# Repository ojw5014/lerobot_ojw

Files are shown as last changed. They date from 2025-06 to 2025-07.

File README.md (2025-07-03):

<p align="center">
  New image
  Open-Snake preview
</p>

# 🤖 Build Your Own Powerful Robot – Affordable & Modular

Ever dreamed of building a fully functional robot using official DYNAMIXEL servos?  
Here’s your chance to do it with a **compact budget and high performance**.

---

## 💰 Total Estimated Cost  
**₩362,778 KRW ≈ $263.17 USD** *(as of June 19, 2025 exchange rate)*  
💡 *That’s the price of a mid-range tablet — but you get a full robot setup!*

---

## 📦 What's Included

| Category | Item | Quantity | Unit Price (KRW) | Subtotal (KRW) | Approx. USD |
|---|---|---|---|---|---|
| **Controller**  | OpenRB-150 | 1 | ₩27,500 | ₩27,500 | $19.95 |
| **Leader Motor**| XL330-M288-T | 6 | ₩26,400 | ₩158,400 | $114.91 |
| **Follower Motors** | XL430-W250-T | 3 | ₩31,900 | ₩95,700 | |
| | XL330-M288-T | 3 | ₩26,400 | ₩79,200 | |
| | **Subtotal (Follower)**  | | | ₩174,900 | $126.88 |
| **Power Supply**| LM317 DC-DC Converter | 2 | ₩1,978 | ₩3,956 | Included |

---

### 💡 Notes
- Prices are based on Korean retail as of **June 19, 2025**.
- USD conversion uses approximate exchange rate of **₩1,378 per $1**.
- Shipping, VAT, or customs not included.

---

## 🎬 Watch It in Action

See the robot moving in real life!

[Click to watch on YouTube](https://youtube.com/shorts/-wr70fOUUQk?si=YxOiGwE313GlAKYQ)

<a href="https://youtube.com/shorts/-wr70fOUUQk?si=YxOiGwE313GlAKYQ" target="_blank">
  Watch on YouTube
</a>

---

## 🧩 How to Assemble LeRobot OJW

Ready to assemble your own LeRobot?

👉 **[Watch the Full Step-by-Step Assembly Video on YouTube](https://youtu.be/AQsma9fiuLw?si=pPNlVMTZPPUCAD57)**

<a href="https://youtu.be/AQsma9fiuLw?si=pPNlVMTZPPUCAD57" target="_blank">
  Assembly Video
</a>

---

## 🛒 Purchase Links

### 🔌 Controller – OpenRB-150  
  
[Buy on Robotis](https://www.robotis.com/shop/item.php?it_id=902-0183-000)

---

### ⚡ Power – LM317 DC-DC Converter  
  
[Buy on AliExpress](https://ko.aliexpress.com/item/1005006562900614.html)

---

### 🤖 Servo Motor – XL330-M288-T  
  
[Buy on Robotis](https://www.robotis.com/shop/item.php?it_id=902-0163-000)

---

### 💪 High-Torque Motor – XL430-W250-T  
  
[Buy on Robotis](https://www.robotis.com/shop/item.php?it_id=902-0135-000)

---

## 🎯 Why This Setup?
- ✅ **Budget-Friendly**: Professional-grade servos at a hobbyist-friendly price  
- 🔧 **Modular & Expandable**: Build, test, and evolve your robot  
- 📚 **Perfect for Education, Research, and Prototyping**  
- 🛠️ **All official parts** – No knockoffs, just reliability

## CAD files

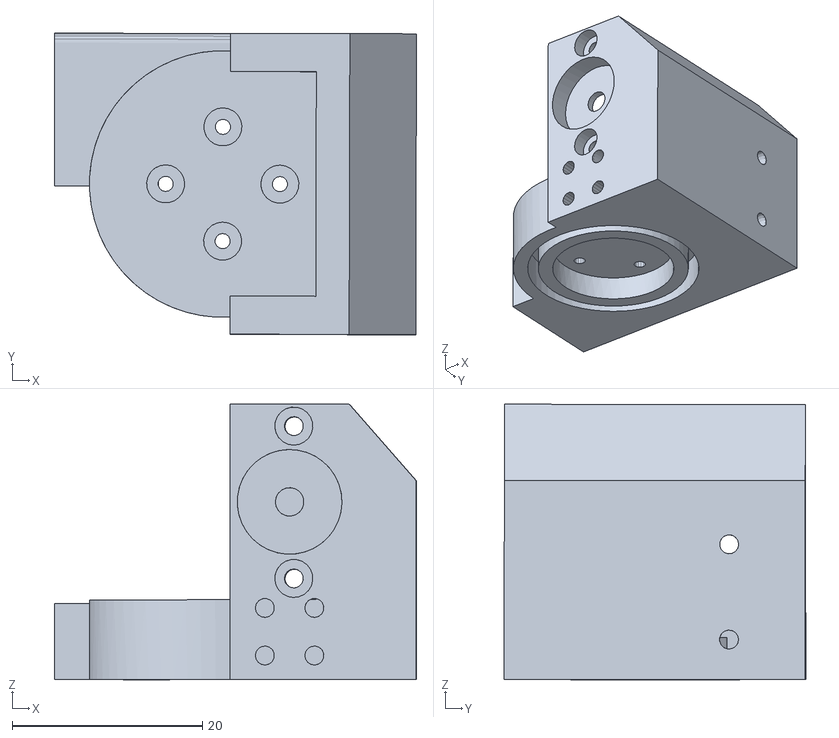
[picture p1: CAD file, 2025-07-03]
lerobot_ojw_stl_v1.1/follower/hand2_base.stl
38.0 x 31.7 x 28.9

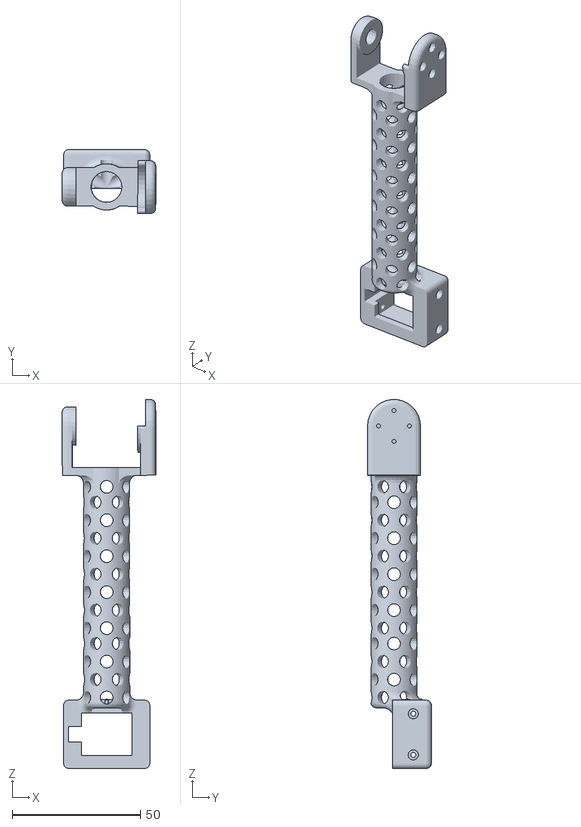
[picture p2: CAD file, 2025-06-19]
lerobot_ojw_stl_v1.1/leader/leader_2.stl
36.5 x 24.9 x 143.6

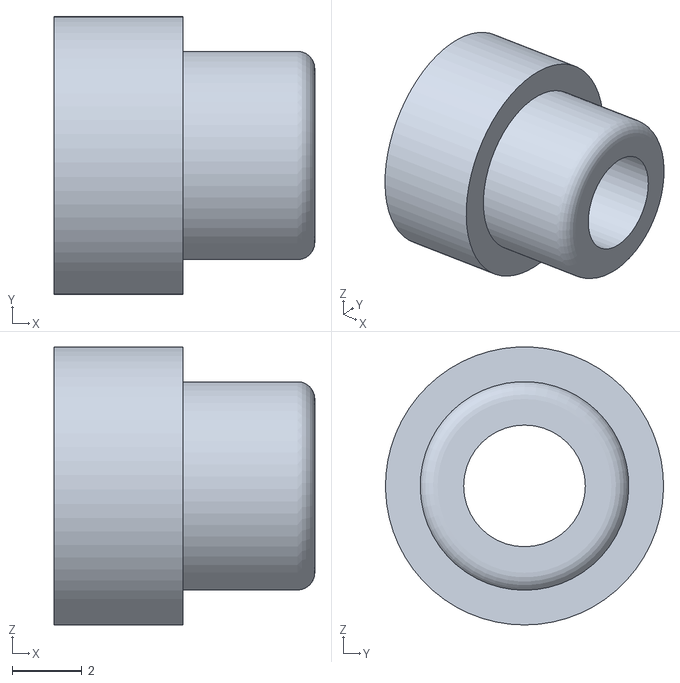
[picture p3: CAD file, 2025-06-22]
lerobot_ojw_stl_v1.1/x330_horn.stl
7.50 x 8.00 x 7.99

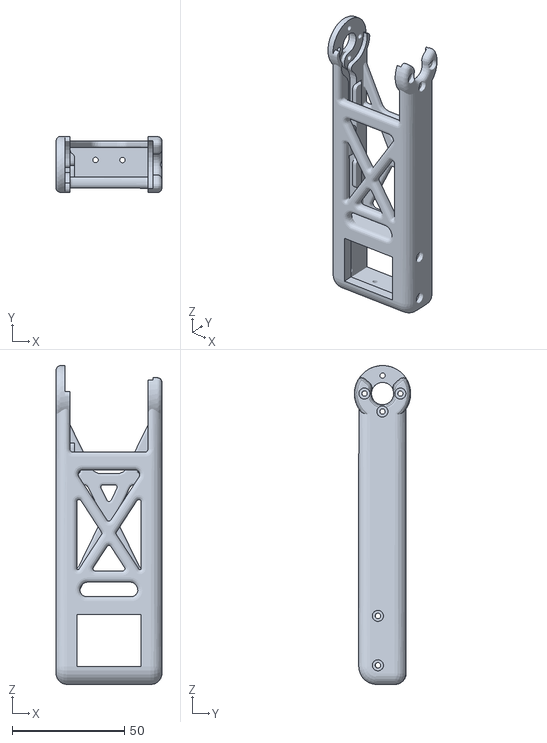
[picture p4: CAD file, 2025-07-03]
lerobot_ojw_stl_v1.1/follower/follower_2.stl
47.3 x 25.1 x 142.0

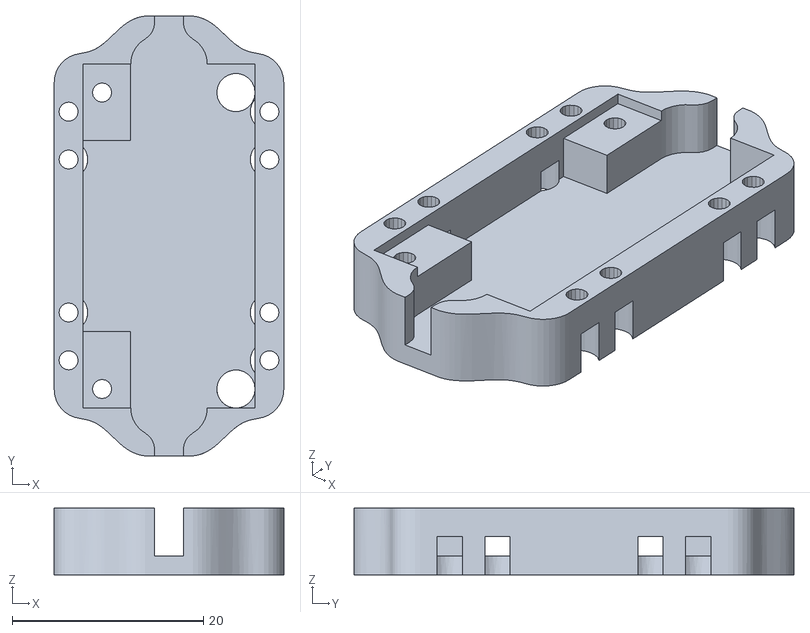
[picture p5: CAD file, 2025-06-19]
lerobot_ojw_stl_v1.1/leader/dcdc_cover_bottom.stl
24.0 x 46.0 x 7.00

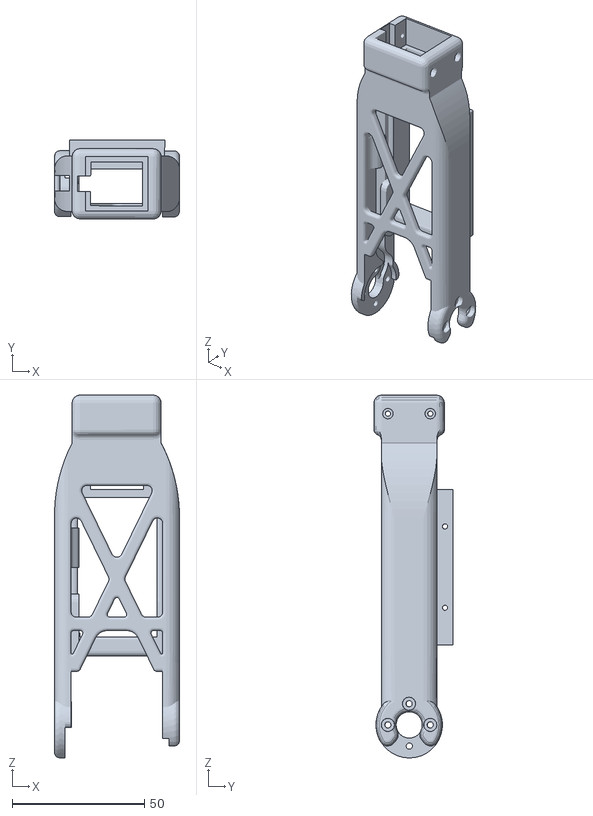
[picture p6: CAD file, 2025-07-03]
lerobot_ojw_stl_v1.1/follower/follower_3.stl
47.3 x 29.9 x 137.1

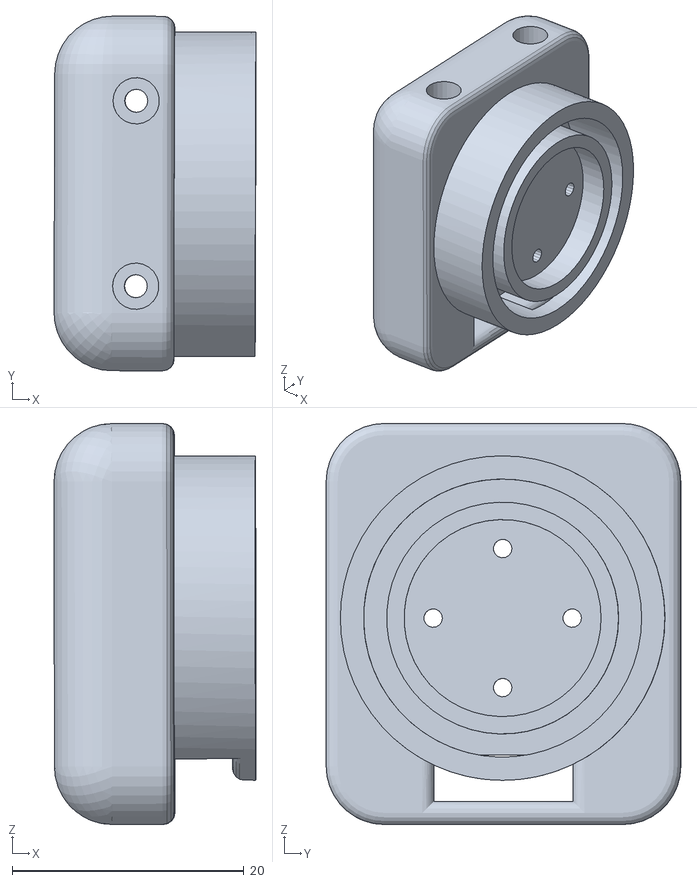
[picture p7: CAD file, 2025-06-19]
lerobot_ojw_stl_v1.1/leader/leader_4.stl
17.4 x 30.6 x 34.6

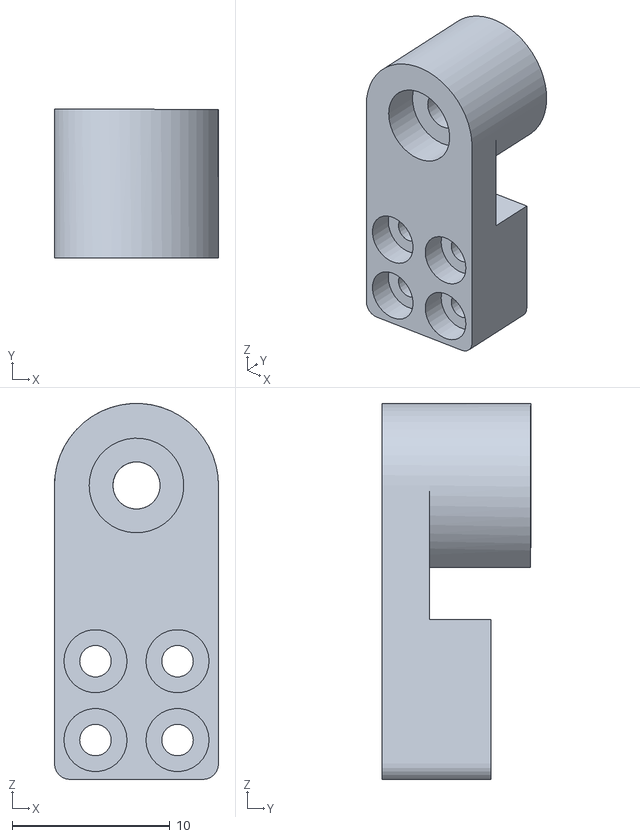
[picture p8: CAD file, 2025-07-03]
lerobot_ojw_stl_v1.1/follower/hand2_guide.stl
10.4 x 9.43 x 23.8

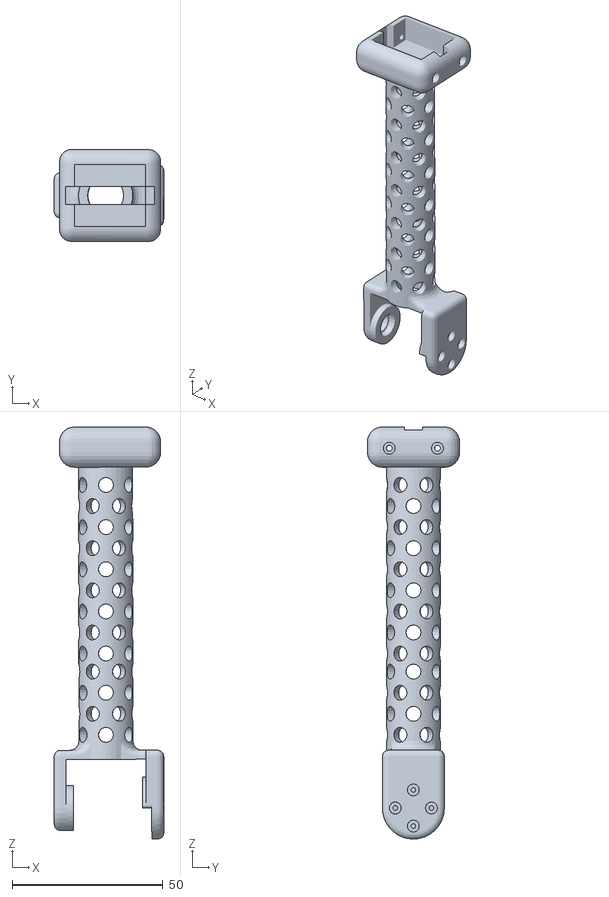
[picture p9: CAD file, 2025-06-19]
lerobot_ojw_stl_v1.1/leader/leader_3.stl
36.5 x 30.7 x 136.8

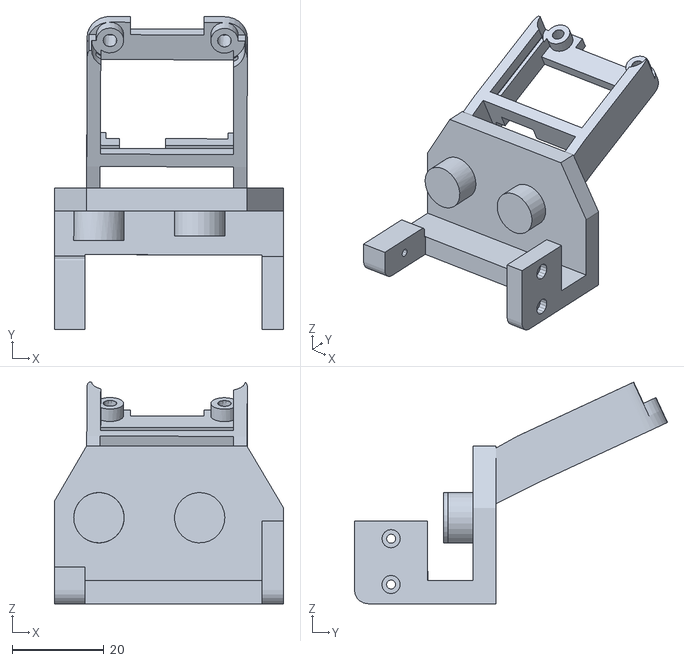
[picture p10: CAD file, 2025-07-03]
lerobot_ojw_stl_v1.1/follower/hand2_Camera.stl
50.0 x 68.4 x 48.4

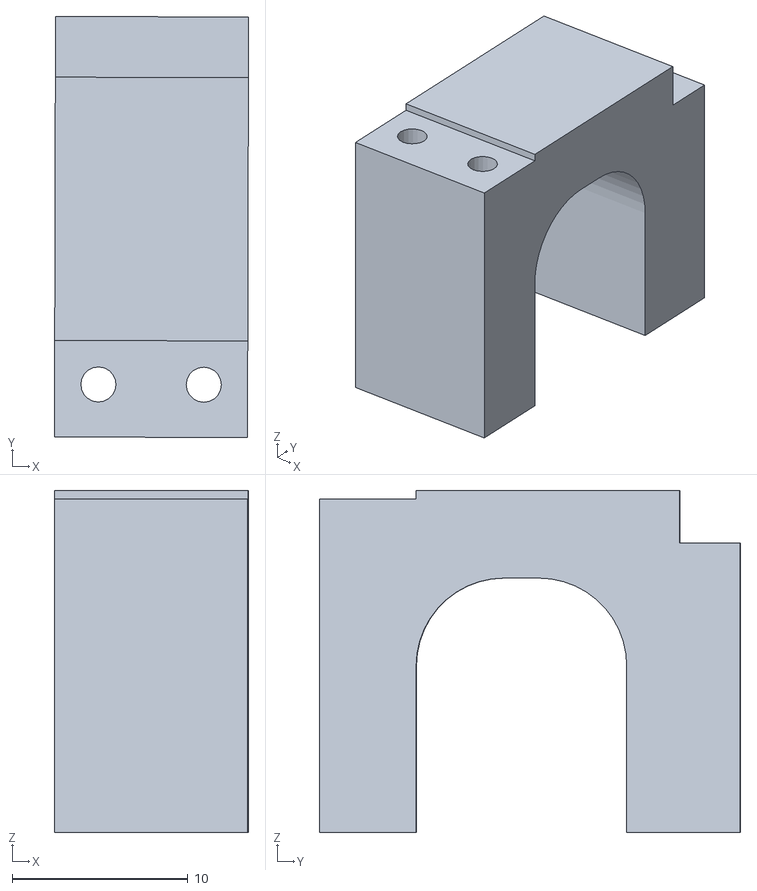
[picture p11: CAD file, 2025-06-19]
lerobot_ojw_stl_v1.1/leader/leader_gun_part_slot.stl
11.1 x 24.0 x 19.5

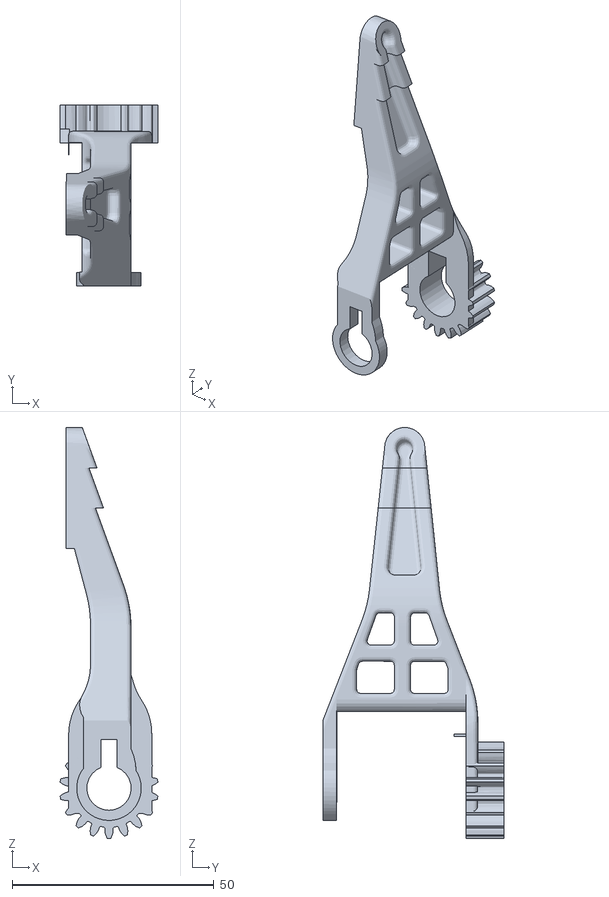
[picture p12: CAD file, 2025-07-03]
lerobot_ojw_stl_v1.1/follower/finger2_dummy.stl
24.3 x 44.9 x 101.9

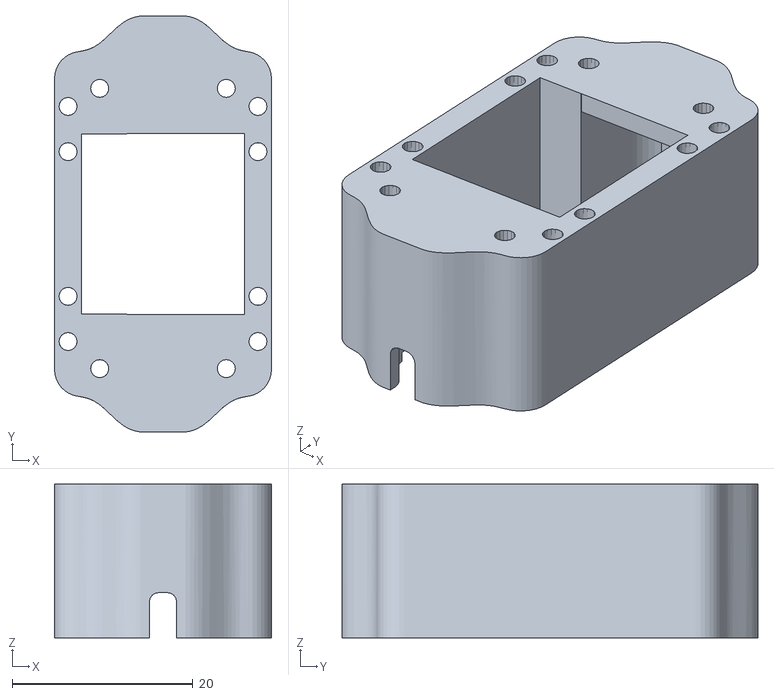
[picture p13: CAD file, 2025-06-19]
lerobot_ojw_stl_v1.1/leader/dcdc_cover_top.stl
24.0 x 46.0 x 17.0

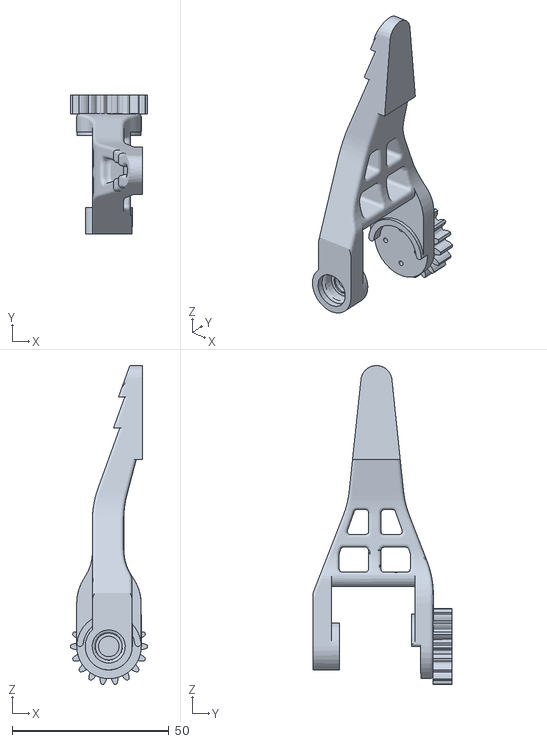
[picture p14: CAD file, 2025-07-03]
lerobot_ojw_stl_v1.1/follower/finger2.stl
24.5 x 44.4 x 101.8

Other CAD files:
lerobot_ojw_stl_v1.1/leader/Release_leg_link.stl
lerobot_ojw_stl_v1.1/follower/follower_4.stl
lerobot_ojw_stl_v1.1/leader/leader_finger.stl
lerobot_ojw_stl_v1.1/follower/follower_3_cover.stl
lerobot_ojw_stl_v1.0/follower/follower_camera_release (1).stl
lerobot_ojw_stl_v1.0/follower/follower_hand0.stl
lerobot_ojw_stl_v1.0/follower/follower_hand1.stl
lerobot_ojw_stl_v1.1/follower/follower_0.stl
lerobot_ojw_stl_v1.1/follower/follower_1.stl
lerobot_ojw_stl_v1.1/leader/leader_0.stl
lerobot_ojw_stl_v1.1/leader/leader_1.stl
lerobot_ojw_stl_v1.1/leader/leader_gun_with_touch.stl

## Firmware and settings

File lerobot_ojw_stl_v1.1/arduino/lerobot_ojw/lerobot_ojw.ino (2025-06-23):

/*

*/
//#include <Dynamixel2Arduino.h>



#include <stdarg.h>
#include <ojw.h>



#define DXL_BUS Serial1
#define USB Serial
#define DXL_PACKET_BUFFER_LENGTH  1024




uint8_t packet_buffer[DXL_PACKET_BUFFER_LENGTH];
unsigned long led_update_time = 0;

//Dynamixel2Arduino dxl(DXL_BUS);

int m_nCmd = 0; // 1 : Command, 0: Usb 2 Dynamixel

int _BTN_TOUCH = 3;

int _ON = LOW;
int _OFF = HIGH;

CProtocol2 m_CMot;
// CTimer m_CTmr;
// CTimer m_CTmr_SW;

void setup() {
  pinMode(_BTN_TOUCH, INPUT);

  USB.begin(57600);

  // m_CTmr.Set();
  ///////////////////////////
  

  // m_CMot.SyncRead("11,12,13,14,15,16");
  // m_CMot.Load("home.txt");
  dxl.begin(USB.baud());
}

void CheckSw()
{
  if (m_nCmd == 1) 
  {
    if (digitalRead(_BTN_TOUCH) == LOW)  
    { 
      //Serial.print("LOW");
      m_CMot.Open(1000000);
      // m_CMot.SetTorq(true);
      m_CMot.SetTorq_On("11,12,13,14,15,16");
      m_CMot.Close();
      //dxl.torqueOn(254);
      m_nCmd = 0;
      // delay(100); // 채터링 방지용
      digitalWrite(LED_BUILTIN, 0);
    }    
  }
  else
  {
    if (digitalRead(_BTN_TOUCH) == HIGH)  
    {
      //Serial.print("HIGH");
      m_CMot.Open(1000000);
      // m_CMot.SetTorq(false);
      m_CMot.SetTorq_Off("11,12,13,14,15,16");
      m_CMot.Close();
      // dxl.torqueOff(254);
      m_nCmd = 1;
      // delay(100); // 채터링 방지용
      digitalWrite(LED_BUILTIN, 1);
    }
  }
}
// ==========================================================================================
// Copyright 2022 ROBOTIS CO., LTD.
//
// Licensed under the Apache License, Version 2.0 (the "License");
// you may not use this file except in compliance with the License.
// You may obtain a copy of the License at
//
//     http://www.apache.org/licenses/LICENSE-2.0
//
// Unless required by applicable law or agreed to in writing, software
// distributed under the License is distributed on an "AS IS" BASIS,
// WITHOUT WARRANTIES OR CONDITIONS OF ANY KIND, either express or implied.
// See the License for the specific language governing permissions and
// limitations under the License.

void loop() {
  CheckSw();
  // if (m_nCmd == 0)
  // {
    // put your main code here, to run repeatedly:
    dataTransceiver();

    if(USB.baud() != dxl.getPortBaud()) {
      dxl.begin(USB.baud());
    }
  // }
  // else
  // {
  // }    
}

void dataTransceiver()
{
  int length = 0;
  int i = 0;

  // USB -> DXL
  length = USB.available();
  if( length > 0 )
  {
    for(i = 0; i < length; i++)
    {
      DXL_BUS.write(USB.read());
    }
    ledStatus();
  }

  // DXL -> USB
  length = DXL_BUS.available();
  if( length > 0 )
  {
    if( length > DXL_PACKET_BUFFER_LENGTH )
    {
      length = DXL_PACKET_BUFFER_LENGTH;
    }
    for(i = 0; i < length; i++)
    {
      packet_buffer[i] = DXL_BUS.read();
    }
    USB.write(packet_buffer, length);
    ledStatus();
  }
}

void ledStatus()
{
  return;
  if((millis() - led_update_time) > 200 )
  {
    digitalWrite(LED_BUILTIN, 1);
    led_update_time = millis();
  } else {
    digitalWrite(LED_BUILTIN, 0);
  }
}

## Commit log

2025-06-19 lerobot_ojw_v1.0 최초 릴리즈
    [Release_leg_link.stl, dcdc_cover_bottom.stl, dcdc_cover_top.stl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]
2025-06-22 horn 부품 추가(빠진것)
    [x330_horn.stl]
2025-06-23 upload - arduino (USB2Dynamixel with touch sensor)
    upload - arduino (USB2Dynamixel with touch sensor)
2025-06-28 최초 커밋 - test - windows
2025-07-03 v1.1 hand_type_2
    [Release_leg_link.stl, dcdc_cover_bottom.stl, dcdc_cover_top.stl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]
